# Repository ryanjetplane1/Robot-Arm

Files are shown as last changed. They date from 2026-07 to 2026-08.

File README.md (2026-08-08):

# 4-Axis Robotic Arm
robot_2026-Jul-27_10-26-27PM-000_CustomizedView28080097244

A BLE controlled robotic arm built on the ESP32-C5. Control it with the website on desktop or on iphone using the Bluefy app.

Four axes of movement, three servos and a stepper for base rotation, controlled from two joysticks over Web Bluetooth or hardcoded macros.

## Overview

This project is a robotic arm with four axes of movement. 2 Bluetooth Low Energy joysticks controls the arm. The arm uses an ESP32-C5 microcontroller. The microcontroller sends commands to three servo motors and one stepper motor. You can control the arm through a web browser or preprogramming with a macro. The web browser uses Web Bluetooth to connect to the arm.

**Features**
- Base, Elbow, Arm, Fingers. Three axes use servo motors. One axis (Base) uses a stepper motor.
- Adjustable control from 2 joysticks.
- Browser based control through Web Bluetooth.
- A preset movement sequence that runs without input.
- A reset command that returns the arm to its home position.
- A command timeout that stops the arm if it stops receiving data.

## Safety

Read this before you build or use the arm.

- The servo motors and the stepper motor move with high force. Keep your hands away from the arm when it is powered.
- Do not exceed 8.4 V on the servo power rail. A higher voltage can damage and fry the servos. (I learned from experience)
- Disconnect the battery before you change wiring.
- If the BLE connection drops, the arm stops all joystick driven movement after 400 milliseconds. This is a safety timeout. Do not rely on it to stop the arm when a macro is running.

## Hardware

### Bill of Materials
| Component | Description | Qty | Price | Link |
|---|---|---|---|---|
| Seeed XIAO ESP32-C5 SuperMini | Main microcontroller | 1 | 12.59$ | [Buy](https://www.aliexpress.us/item/3256811643444390.html) |
| 35kg Servo motor | Drives arm | 3 | 26.99$ | [Buy](https://www.microcenter.com/product/707728/hiwonder-hps-3518sg-high-speed-coreless-servo-35kg-high-torque) |
| 28BYJ-48 stepper motor and ULN2003 driver board | Drives base | 1 | 11.99$ | [Buy](https://www.microcenter.com/product/639726/inland-ks0327-keyestudio-stepper-motor-drive-board-5v-stepper-motor-kit-(3pcs)) |
| 10A 8.4v Power supply | Powers all motors | 1 | 39.99$ | [Buy](https://www.amazon.com/gp/product/B0CRSS744F) |
| XL6019 Buck Boost Converter | Stepper motor power | 1 | 5.99$ | [Buy](https://www.amazon.com/gp/product/B08CHCG79J) |
| | | | **Total: $151.06** | |

The base requires low torque so most steppers will work.

### Wiring

**Servos**

| Servo | Board Pin |
|---|---|
| Servo 1 | D9 |
| Servo 2 | D5 |
| Servo 3 | D4 |

**Stepper (base rotation)**

| Driver | Board Pin |
|---|---|
| IN1 | D0 |
| IN2 | D1 |
| IN3 | D2 |
| IN4 | D3 |

**Power**

| Converter | Stepper Pin |
|---|---|
| IN- | Gnd |
| IN+ | 8.4v |
| Out- | Gnd |
| Out+ | 5v |

wiring diagram

Connect all grounds together including microcontroller and power supply. Connect all servo power wires to 8.4 V. The stepper motor should be powered with 5v. Do not connect the motor power rail to the microcontroller power pin.

## Firmware

The firmware runs on the ESP32-C5. The firmware controls the three servos directly while the stepper motor is controlled with a 4-step sequence.

**Install**
1. Open the firmware project in the Arduino IDE.
2. Install the ESP32Servo library and the ESP32 BLE libraries.
3. Select the board type XIAO ESP32-C5 from the board manager.
4. Connect the microcontroller to your computer with a USB cable.
5. Select the correct serial port.
6. Click Upload to load the firmware onto the microcontroller.

## Usage

**BLE Joystick**

The BLE joystick sends data to the arm over Bluetooth Low Energy. Pair the joystick with the arm before use.

**Web Bluetooth**

Control page: [ryanjetplane1.github.io/Robot-Arm](https://ryanjetplane1.github.io/Robot-Arm/)

1. Open the link above.
2. On iPhone, use the Bluefy browser. Standard iOS browsers do not support Web Bluetooth.
3. Tap Connect on the web page.
4. Select RobotArm from the device list.
5. Use the on-screen controls to move the arm.

If the connection fails with a "failed undefined" error, close and reopen the Bluefy browser, then try again.

## Assembly

**How to build**
Step 0: Lay out parts

Step 1: Insert the motor

Step 2: Push in the base

Step 3: Insert parts and slot in box

Step 4: Push in servo mount 1

Step 5: Push in servo mount 2

Step 6: Insert servos and grippers


F3D can be found in the releases section.

Demo video
https://m.youtube.com/watch?v=tXdHmja3yAY&feature=youtu.be

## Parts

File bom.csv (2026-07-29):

Component | Description | Qty | Price | Link
Seeed XIAO ESP32-C5 SuperMini | Main microcontroller | 1 | 12.59 | https://www.aliexpress.us/item/3256811643444390.html
35kg Servo motor | Drives arm | 3 | 26.99 | https://www.microcenter.com/product/707728/hiwonder-hps-3518sg-high-speed-coreless-servo-35kg-high-torque
28BYJ-48 stepper motor and ULN2003 driver board | Drives base | 1 | 11.99 | https://www.microcenter.com/product/639726/inland-ks0327-keyestudio-stepper-motor-drive-board-5v-stepper-motor-kit-(3pcs)
10A 8.4v Power supply | Powers all motors | 1 | 39.99 | https://www.amazon.com/gp/product/B0CRSS744F
XL6019 Buck Boost Converter | Stepper motor power | 1 | 5.99 | https://www.amazon.com/gp/product/B08CHCG79J
Total |  |  | 151.53

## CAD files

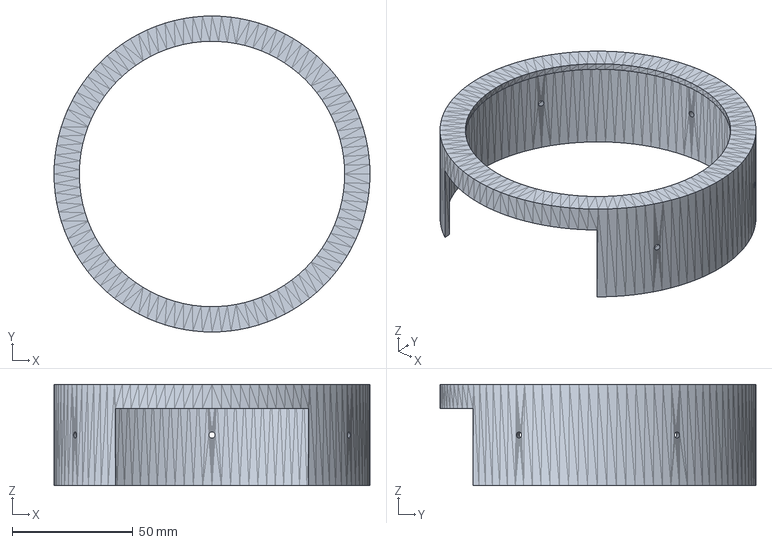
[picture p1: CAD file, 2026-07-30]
cad/Cadstep/3.step
131.0 x 131.0 x 42.0 mm

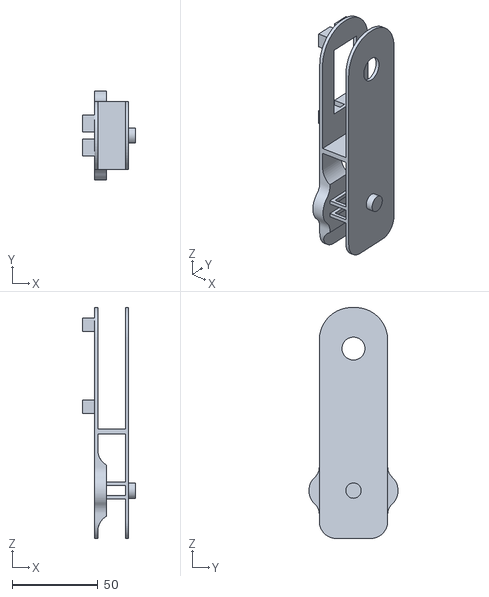
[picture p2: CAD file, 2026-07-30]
cad/Cadstl/7.stl
31.0 x 52.0 x 135.0

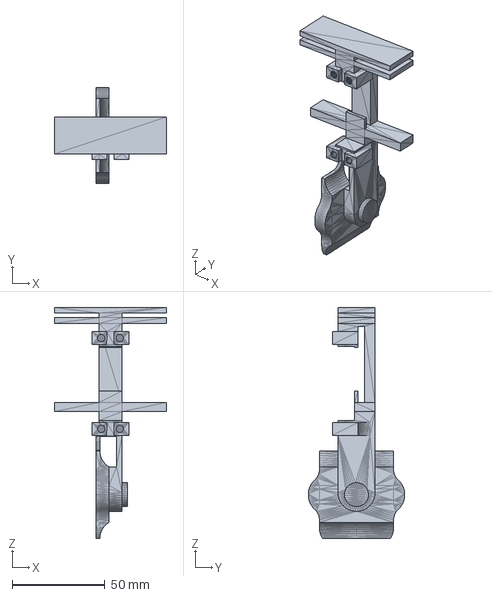
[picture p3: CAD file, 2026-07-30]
cad/Cadstep/8.step
60.5 x 52.0 x 124.7 mm

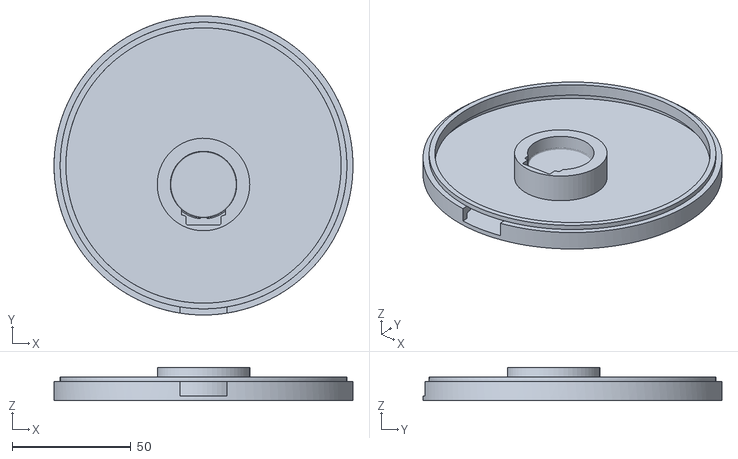
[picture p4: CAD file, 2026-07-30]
cad/Cadstl/4.stl
126.0 x 126.0 x 14.0

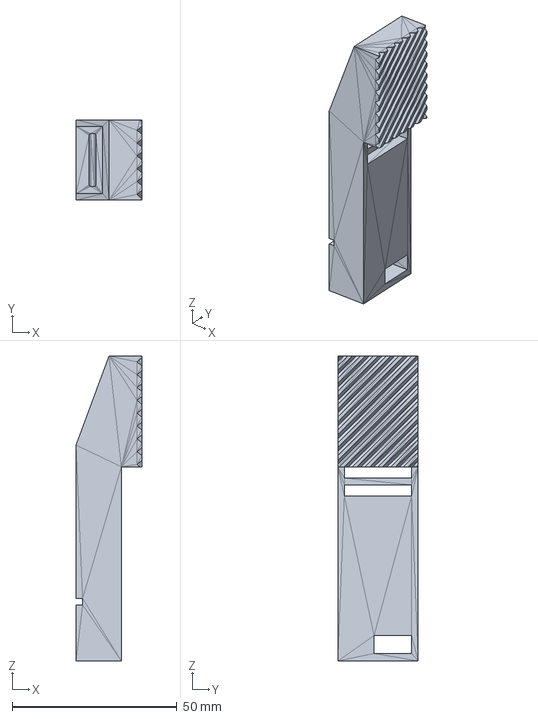
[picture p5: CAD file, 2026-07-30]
cad/Cadstep/9.step
20.0 x 24.4 x 92.5 mm

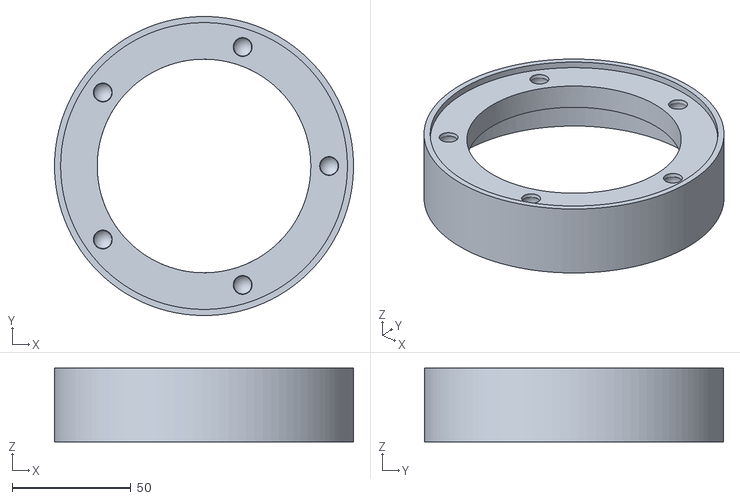
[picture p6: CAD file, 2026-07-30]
cad/Cadstl/5.stl
126.0 x 126.0 x 31.0

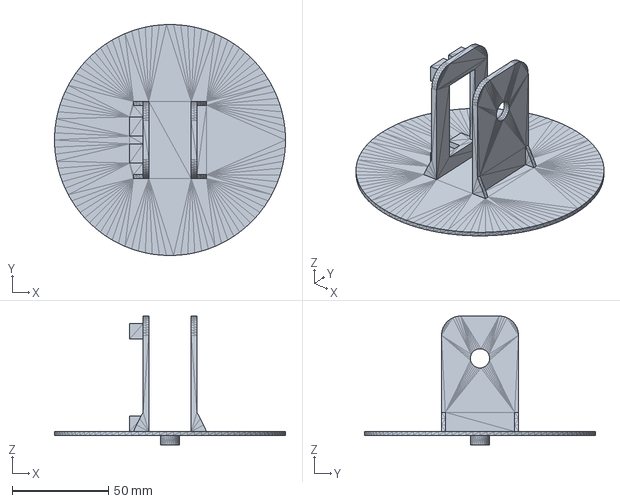
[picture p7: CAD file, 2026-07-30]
cad/Cadstep/6.step
120.0 x 119.9 x 67.0 mm

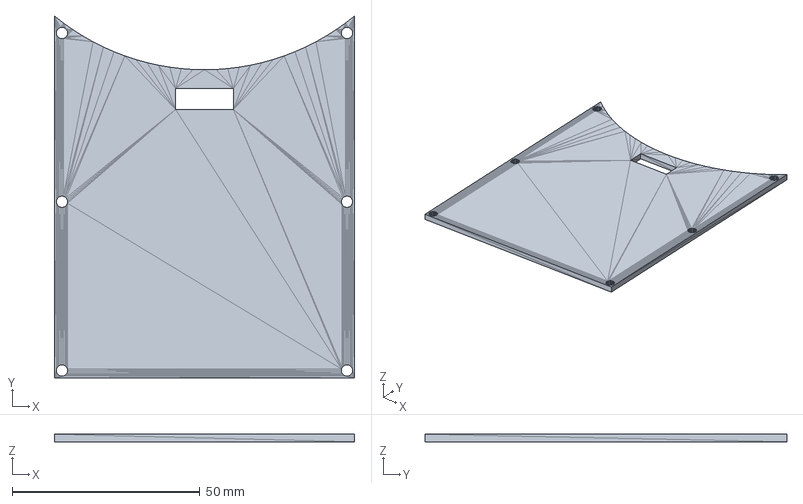
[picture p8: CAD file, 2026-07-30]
cad/Cadstep/2.step
80.0 x 96.5 x 2.00 mm

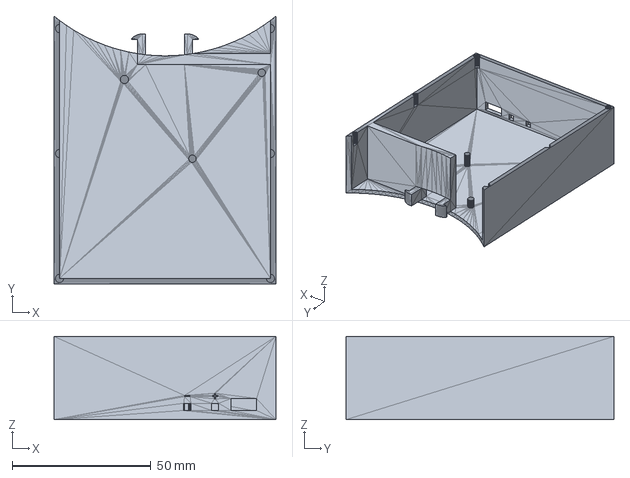
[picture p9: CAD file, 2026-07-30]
cad/Cadstep/1.step
80.0 x 96.5 x 30.0 mm

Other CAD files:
cad/Cadstep/10.step
cad/Cadstl/1.stl
cad/Cadstl/10.stl
cad/Cadstl/2.stl
cad/Cadstl/3.stl
cad/Cadstl/6.stl
cad/Cadstl/8.stl
cad/Cadstl/9.stl

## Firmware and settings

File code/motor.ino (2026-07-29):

#include <ESP32Servo.h>
#include <BLEDevice.h>
#include <BLEUtils.h>
#include <BLEServer.h>

#define SERVICE_UUID        "4FAFC201-1FB5-459E-8FCC-C5C9C331914B"
#define CHARACTERISTIC_UUID "19B10001-E8F2-537E-4F6C-D104768A1214"

BLEServer* pServer = NULL;
BLECharacteristic* pCharacteristic = NULL;
bool deviceConnected = false;
String pendingData = "";
volatile bool hasNewData = false;

Servo servo1; Servo servo2; Servo servo3;
float current_s1 = 90.0; float current_s2 = 90.0; float current_s3 = 90.0;

const int IN1 = D0; const int IN2 = D1; const int IN3 = D2; const int IN4 = D3;
int stepIndex = 0;
long stepperCount = 0;
bool isResetActive = false;

int target_lx = 0, target_ly = 0, target_rx = 0, target_ry = 0;
unsigned long lastStepTime = 0;
unsigned long lastServoTime = 0;
const unsigned long STEP_INTERVAL_US = 2500;
const unsigned long SERVO_INTERVAL_MS = 20;

unsigned long lastCommandMillis = 0;
const unsigned long COMMAND_TIMEOUT_MS = 400;

enum MacroState {
  MACRO_IDLE,
  MACRO_RAMP_UP,
  MACRO_LOWER_WAIT,
  MACRO_TILT_DOWN,
  MACRO_TILT_DOWN_WAIT,
  MACRO_TILT_UP_WAIT,
  MACRO_STEP_CCW_1,
  MACRO_WAIT_1,
  MACRO_STEP_CW,
  MACRO_WAIT_2,
  MACRO_STEP_CCW_2,
  MACRO_WAIT_3,
  MACRO_RAMP_DOWN
};

MacroState macroState = MACRO_IDLE;
unsigned long macroTimer = 0;
int macroOffset = 0;
long macroStepsDone = 0;
unsigned long macroStepTimer = 0;

void takeSingleStep(bool clockwise) {
  int lookup[4][4] = {
    {HIGH, LOW, LOW, LOW}, {LOW, HIGH, LOW, LOW},
    {LOW, LOW, HIGH, LOW}, {LOW, LOW, LOW, HIGH}
  };
  if (clockwise) {
    stepIndex++; if (stepIndex > 3) stepIndex = 0;
    stepperCount++;
  } else {
    stepIndex--; if (stepIndex < 0) stepIndex = 3;
    stepperCount--;
  }
  digitalWrite(IN1, lookup[stepIndex][0]);
  digitalWrite(IN2, lookup[stepIndex][1]);
  digitalWrite(IN3, lookup[stepIndex][2]);
  digitalWrite(IN4, lookup[stepIndex][3]);
}

void disableStepperCoils() {
  digitalWrite(IN1, LOW); digitalWrite(IN2, LOW);
  digitalWrite(IN3, LOW); digitalWrite(IN4, LOW);
}

void startMacro1() {
  if (macroState != MACRO_IDLE) return;
  macroOffset = 0;
  macroState = MACRO_RAMP_UP;
}

void serviceMacro1() {
  unsigned long now = millis();

  switch (macroState) {
    case MACRO_IDLE:
      return;

    case MACRO_RAMP_UP:
      servo3.write(90);
      if (now - lastServoTime >= 40) {
        lastServoTime = now;
        servo2.write(90 - macroOffset);
        servo1.write(90 + macroOffset);
        macroOffset++;
        if (macroOffset > 45) {
          macroTimer = now;
          macroState = MACRO_LOWER_WAIT;
        }
      }
      break;

    case MACRO_LOWER_WAIT:
      if (now - macroTimer >= 1000) {
        servo3.write(0);
        macroTimer = now;
        macroState = MACRO_TILT_DOWN_WAIT;
      }
      break;

    case MACRO_TILT_DOWN_WAIT:
      if (now - macroTimer >= 2000) {
        servo3.write(90);
        macroTimer = now;
        macroState = MACRO_TILT_UP_WAIT;
      }
      break;

    case MACRO_TILT_UP_WAIT:
      if (now - macroTimer >= 2000) {
        macroStepsDone = 0;
        macroStepTimer = now;
        macroState = MACRO_STEP_CCW_1;
      }
      break;

    case MACRO_STEP_CCW_1:
      servo3.write(90);
      if (now - macroStepTimer >= 4) {
        macroStepTimer = now;
        takeSingleStep(false);
        macroStepsDone++;
        if (macroStepsDone >= 200) {
          disableStepperCoils();
          macroTimer = now;
          macroState = MACRO_WAIT_1;
        }
      }
      break;

    case MACRO_WAIT_1:
      if (now - macroTimer >= 1000) {
        macroStepsDone = 0;
        macroStepTimer = now;
        macroState = MACRO_STEP_CW;
      }
      break;

    case MACRO_STEP_CW:
      servo3.write(90);
      if (now - macroStepTimer >= 4) {
        macroStepTimer = now;
        takeSingleStep(true);
        macroStepsDone++;
        if (macroStepsDone >= 400) {
          disableStepperCoils();
          macroTimer = now;
          macroState = MACRO_WAIT_2;
        }
      }
      break;

    case MACRO_WAIT_2:
      if (now - macroTimer >= 1000) {
        macroStepsDone = 0;
        macroStepTimer = now;
        macroState = MACRO_STEP_CCW_2;
      }
      break;

    case MACRO_STEP_CCW_2:
      servo3.write(90);
      if (now - macroStepTimer >= 4) {
        macroStepTimer = now;
        takeSingleStep(false);
        macroStepsDone++;
        if (macroStepsDone >= 200) {
          disableStepperCoils();
          macroTimer = now;
          macroState = MACRO_WAIT_3;
        }
      }
      break;

    case MACRO_WAIT_3:
      if (now - macroTimer >= 1000) {
        macroOffset = 45;
        macroState = MACRO_RAMP_DOWN;
      }
      break;

    case MACRO_RAMP_DOWN:
      if (now - lastServoTime >= 40) {
        lastServoTime = now;
        servo2.write(90 - macroOffset);
        servo1.write(90 + macroOffset);
        macroOffset--;
        if (macroOffset < 0) {
          current_s1 = 90.0; current_s2 = 90.0; current_s3 = 90.0;
          target_lx = 0; target_ly = 0; target_rx = 0; target_ry = 0;
          macroState = MACRO_IDLE;
        }
      }
      break;
  }
}

void parseStreamData(String data) {
  data.trim();
  if (data.length() == 0) return;
  if (data == "MACRO1") { startMacro1(); return; }
  if (data == "RESET") {
    macroState = MACRO_IDLE;
    isResetActive = true;
    current_s1 = 90.0; current_s2 = 90.0; current_s3 = 90.0;
    servo1.write(90); servo2.write(90); servo3.write(90);
    return;
  }

  int firstComma = data.indexOf(',');
  int secondComma = data.indexOf(',', firstComma + 1);
  int thirdComma = data.indexOf(',', secondComma + 1);
  if (firstComma == -1 || secondComma == -1 || thirdComma == -1) return;

  target_lx = data.substring(0, firstComma).toInt();
  target_ly = data.substring(firstComma + 1, secondComma).toInt();
  target_rx = data.substring(secondComma + 1, thirdComma).toInt();
  target_ry = data.substring(thirdComma + 1).toInt();
  lastCommandMillis = millis();
}

class MyServerCallbacks: public BLEServerCallbacks {
    void onConnect(BLEServer* pServer) { deviceConnected = true; };
    void onDisconnect(BLEServer* pServer) { deviceConnected = false; pServer->getAdvertising()->start(); }
};

class MyCallbacks: public BLECharacteristicCallbacks {
    void onWrite(BLECharacteristic *pCharacteristic) {
      String value = pCharacteristic->getValue();
      if (value.length() > 0) { pendingData = value; hasNewData = true; }
    }
};

void setup() {
  Serial.begin(115200);
  servo1.attach(D9); servo2.attach(D5); servo3.attach(D4);
  pinMode(IN1, OUTPUT); pinMode(IN2, OUTPUT); pinMode(IN3, OUTPUT); pinMode(IN4, OUTPUT);
  disableStepperCoils();
  servo1.write(90); servo2.write(90); servo3.write(90);

  BLEDevice::init("RobotArm");
  BLEDevice::setMTU(247);
  pServer = BLEDevice::createServer();
  pServer->setCallbacks(new MyServerCallbacks());
  BLEService *pService = pServer->createService(SERVICE_UUID);
  pCharacteristic = pService->createCharacteristic(CHARACTERISTIC_UUID, BLECharacteristic::PROPERTY_WRITE | BLECharacteristic::PROPERTY_WRITE_NR);
  pCharacteristic->setCallbacks(new MyCallbacks());
  pService->start();
  BLEAdvertising *pAdvertising = BLEDevice::getAdvertising();
  pAdvertising->addServiceUUID(SERVICE_UUID);
  pAdvertising->setScanResponse(true);
  pAdvertising->setMinPreferred(0x06);
  pAdvertising->setMinPreferred(0x12);
  BLEDevice::startAdvertising();
}

void loop() {
  if (hasNewData) {
    hasNewData = false;
    parseStreamData(pendingData);
  }

  if (macroState == MACRO_IDLE && !isResetActive &&
      lastCommandMillis != 0 &&
      millis() - lastCommandMillis > COMMAND_TIMEOUT_MS) {
    target_lx = 0; target_ly = 0; target_rx = 0; target_ry = 0;
  }

  serviceMacro1();

  unsigned long currentMicros = micros();
  unsigned long currentMillis = millis();

  if (isResetActive) {
    if (stepperCount != 0) {
      if (currentMicros - lastStepTime >= STEP_INTERVAL_US) {
        takeSingleStep(stepperCount <= 0);
        lastStepTime = currentMicros;
      }
    } else {
      disableStepperCoils();
      if (target_lx == 0 && target_ly == 0 && target_rx == 0 && target_ry == 0) {
        isResetActive = false;
      }
    }
  } else if (macroState == MACRO_IDLE) {
    if (target_lx > 30) {
      if (currentMicros - lastStepTime >= STEP_INTERVAL_US) { takeSingleStep(true); lastStepTime = currentMicros; }
    } else if (target_lx < -30) {
      if (currentMicros - lastStepTime >= STEP_INTERVAL_US) { takeSingleStep(false); lastStepTime = currentMicros; }
    } else {
      disableStepperCoils();
    }
  }

  if (!isResetActive && macroState == MACRO_IDLE && (currentMillis - lastServoTime >= SERVO_INTERVAL_MS)) {
    lastServoTime = currentMillis;

    if (abs(target_ly) > 25) {
      current_s1 -= (target_ly / 100.0) * 1.0;
    }
    if (abs(target_ry) > 25) {
      current_s2 -= (target_ry / 100.0) * 1.0;
    }
    if (abs(target_rx) > 25) {
      current_s3 -= (target_rx / 100.0) * 1.5;
    }

    current_s1 = constrain(current_s1, 0.0, 180.0);
    current_s2 = constrain(current_s2, 0.0, 180.0);
    current_s3 = constrain(current_s3, 0.0, 180.0);

    servo1.write((int)current_s1);
    servo2.write((int)current_s2);
    servo3.write((int)current_s3);
  }
}

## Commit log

2026-07-29 Remove code formatting from device selection step
2026-07-29 Add bill of materials for project components
    [bom.csv]
2026-07-29 Add motor control and BLE functionality
2026-07-29 Add image to README for 4-Axis Robotic Arm
    Added an image to the README for better visualization.
2026-07-30 Update README with assembly and build instructions
    Added assembly instructions and build information to README.
2026-07-31 Update assembly steps in README
2026-08-06 Modify bill of materials and update total cost
    Updated the bill of materials to include a WiFi antenna and adjusted the total cost.
2026-08-07 Update BOM by removing unnecessary WiFi antenna
    Removed the 2.4/5.8GHz Dual Band WiFi Antenna from the BOM as it is not necessary.
